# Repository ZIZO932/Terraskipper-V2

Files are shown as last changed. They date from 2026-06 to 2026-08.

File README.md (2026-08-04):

# Terraskipper V2 

> A mudskipper-inspired soft robot built to help farmers monitor and understand their soil

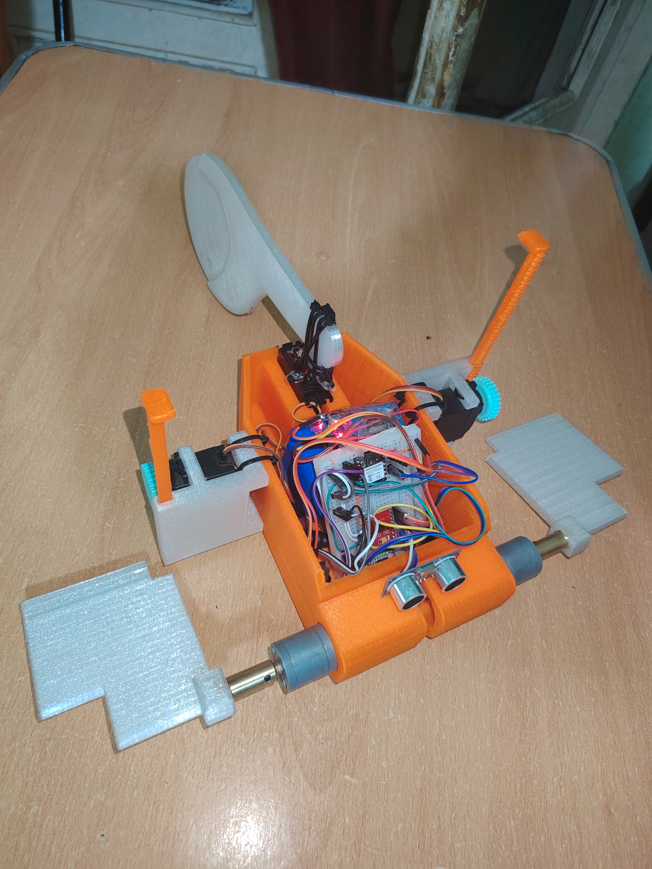
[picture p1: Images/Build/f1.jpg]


---

## What is this?

Terraskipper is a robot that moves like a mudskipper fish. It crawls on mud and uneven ground using fins powered by DC motors and servos. While it moves around it collects soil data like pH levels, moisture, salinity and other environmental readings.

The whole idea came from a real problem. The Nile Delta in Egypt is facing serious soil degradation. Salt levels are rising and pH is shifting in ways that hurt farming. Most monitoring tools cant really reach difficult terrain or muddy areas. Terraskipper can.

The robot is designed to go where normal sensors cant and give farmers useful data about their land without them having to do much.

---

## Why I made it

I wanted to build something that actually solves a problem in the real world not just a cool robot for the sake of it. Agriculture in Egypt especially near the Nile Delta depends on soil quality and right now that soil is changing in ways that are hard to track.

A mudskipper felt like the perfect inspiration because it literally evolved to handle the transition between water and land which is exactly the kind of terrain that is hard for robots to deal with.

---

## Build Process

After the design was done I moved on to actually building it. A lot of stuff that worked on screen didnt work the same in real life.

- Rebuilt the circuit from the schematic one component at a time, testing power, then the Pico, then each sensor one by one (moisture, TDS, temperature, the 3 ultrasonics) so debugging was easier.
- Got PCB review feedback: add screw mounting, clean up and round the layout, include Gerber files, add the missing sensors to the CAD. Fixed all of it and gave the PCB its own mounting spot in the 3D model.
- Assembled the robot: joined the two printed body halves, built the sensor placement mechanism, mounted the motors and fins, then fit the PCB and wired everything inside the body.
- Tested the full system and tested power, sensors, and movement again after assembly to catch anything that shifted.
- Uploaded and ran the code function by function. Found the right DC motor wasnt moving, swapped both motors to confirm it wasnt the motor itself, traced it to the motor driver's motor B output, and fixed it.
- Did a final pass before filming: checked all connections, cleaned up the wiring, and ran through the movements a few times to make sure they'd look good on camera.

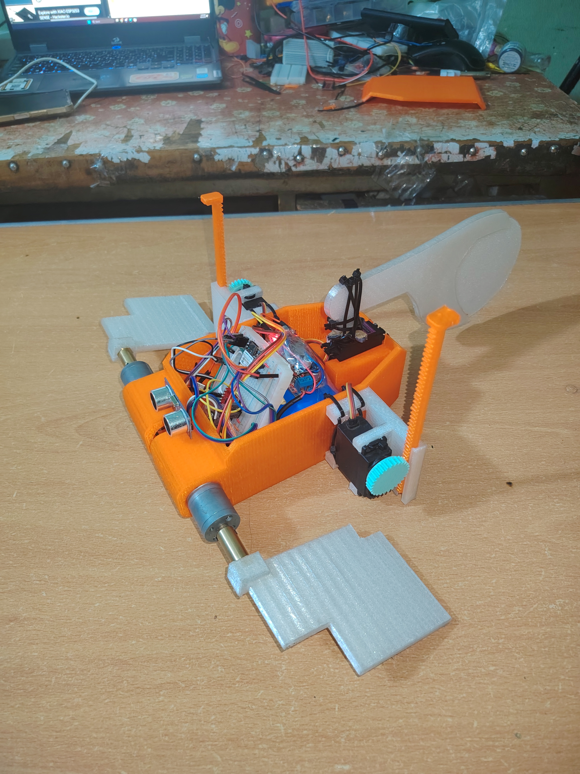
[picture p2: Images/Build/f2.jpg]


---

## The Final Build

after the first prototype i went back and reprinted the whole body smaller than before. still fits everything inside the same as before, just uses less filament and ends up alot lighter overall. checked all the parts lined up right after printing and made a couple small tweaks where they didnt.

that was really the only change from the first prototype to the final one, just the size.

---

## How it works

The robot has two main systems working together

**Movement system**
- Two JGB37-520 DC Geared Motors (12V 37RPM with encoders) power the pectoral fins for forward movement
- One servo controls the caudal fin for steering
- Two more servos handle the sensor placement mechanism so the sensors can move up and down to properly contact the soil

**Sensor system**
- 3x HC-SR04 ultrasonic sensors for obstacle detection and movement awareness (removed two in the final because one of them wasnt working for no reason)
- MPU-6050 IMU for tilt and orientation tracking using gyroscope and accelerometer
- Ublox NEO-7M GPS module for location tracking
- Capacitive soil moisture sensor V2.0 for soil water content readings
- DS18B20 waterproof temperature sensor for soil temperature

**Brain**
- Raspberry Pi Pico 2 W handles everything

---

## The 3D Model

For the body i made sure that all edges have fillets and chamfers so the robot doesnt damage the soil while crawling.

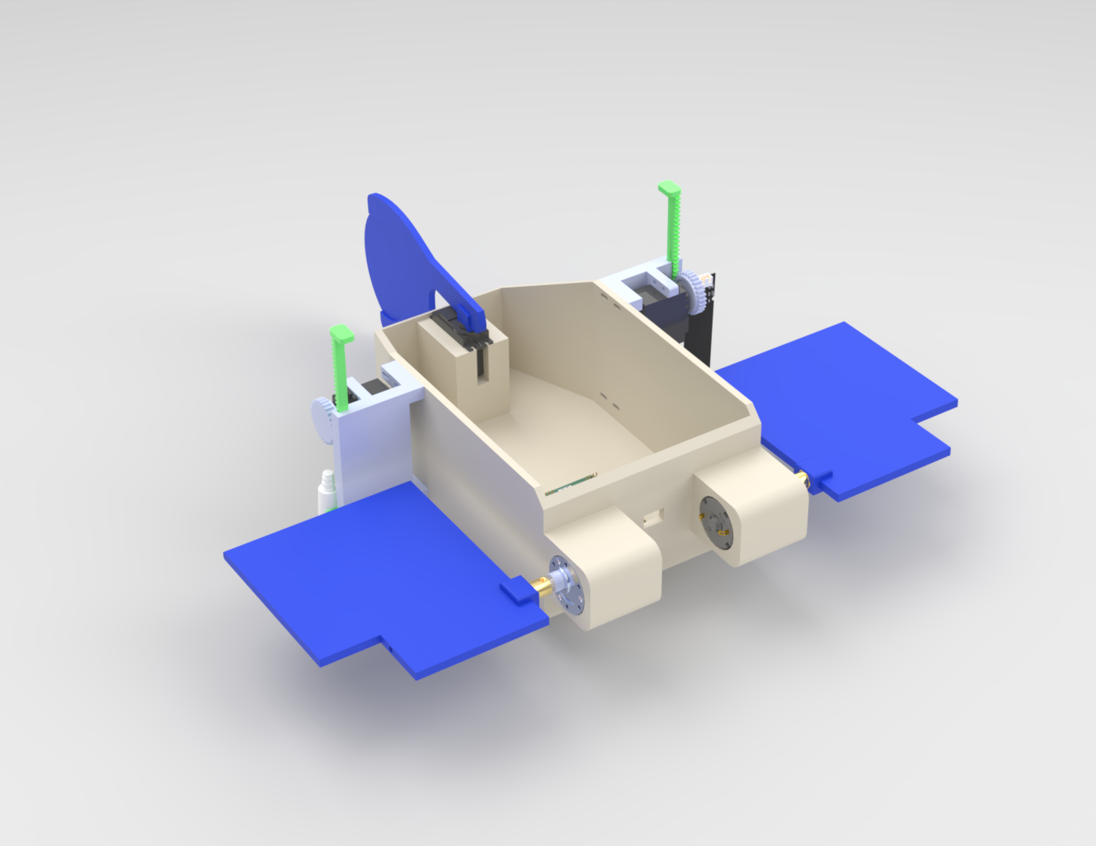
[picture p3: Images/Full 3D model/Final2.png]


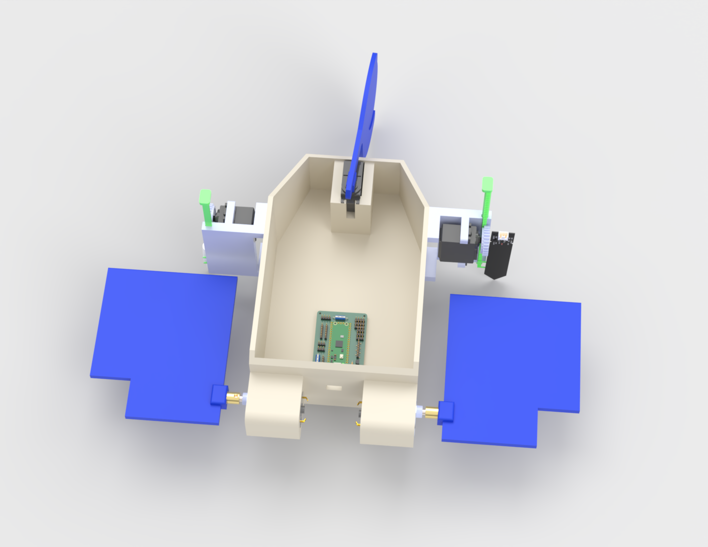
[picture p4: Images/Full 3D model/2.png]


The sensor placement mechanism uses a mini linear slider with a servo motor so the sensors can move vertically and make proper contact with different soil surfaces. The mechanism is also detachable so it can be removed for repairs without taking apart the whole robot.

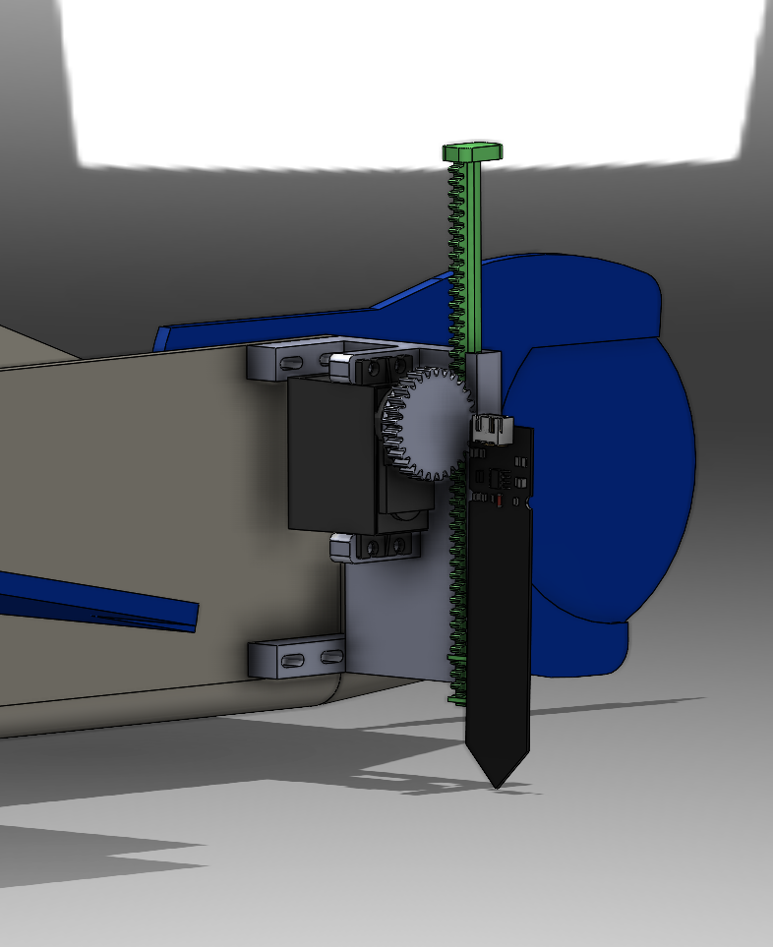
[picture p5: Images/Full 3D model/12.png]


---

## PCB & Electronics

The PCB is a 2-layer board. Top layer carries signal lines and positive voltage. Bottom layer is a full GND plane to keep things clean and reduce noise.

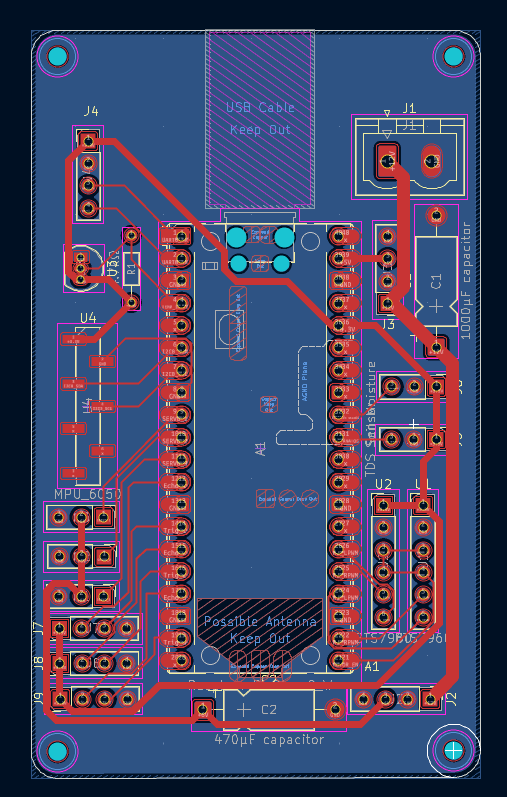
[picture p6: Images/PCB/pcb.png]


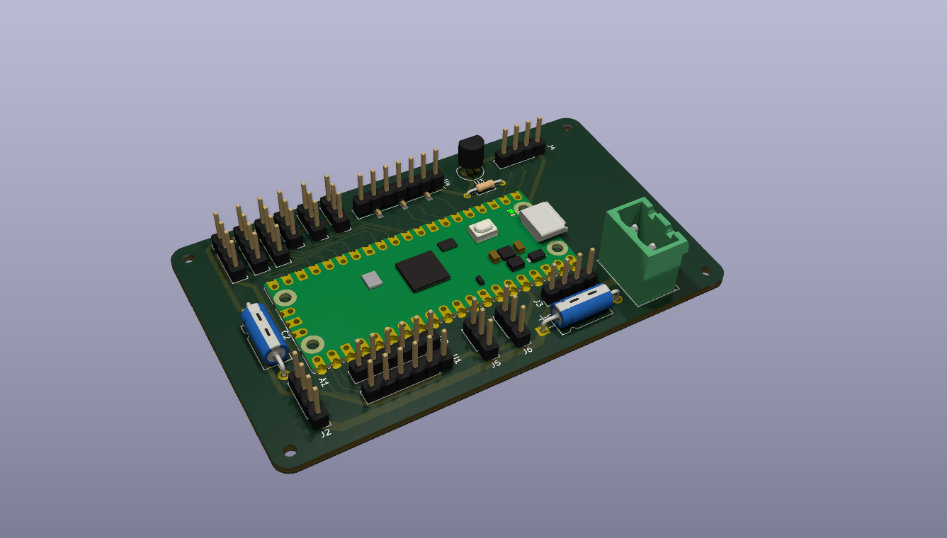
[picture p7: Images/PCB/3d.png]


Main components on the board:

- Xiao esp S3
- 2x BTS7960 43A motor drivers (one per DC motor)
- XL4016 8A and LM2596 3A buck converters for power regulation
- MPU-6050 IMU gyro and accelerometer
- Ublox NEO-7M GPS module
- Capacitive soil moisture sensor V2.0
- DS18B20 waterproof temperature sensor
- 3x HC-SR04 ultrasonic sensors

All sensors run on 3.3V logic to match the Pico 2 W. Power comes from the buck converters and sensors pull directly from the Pico 3.3V output.

---

## Wiring

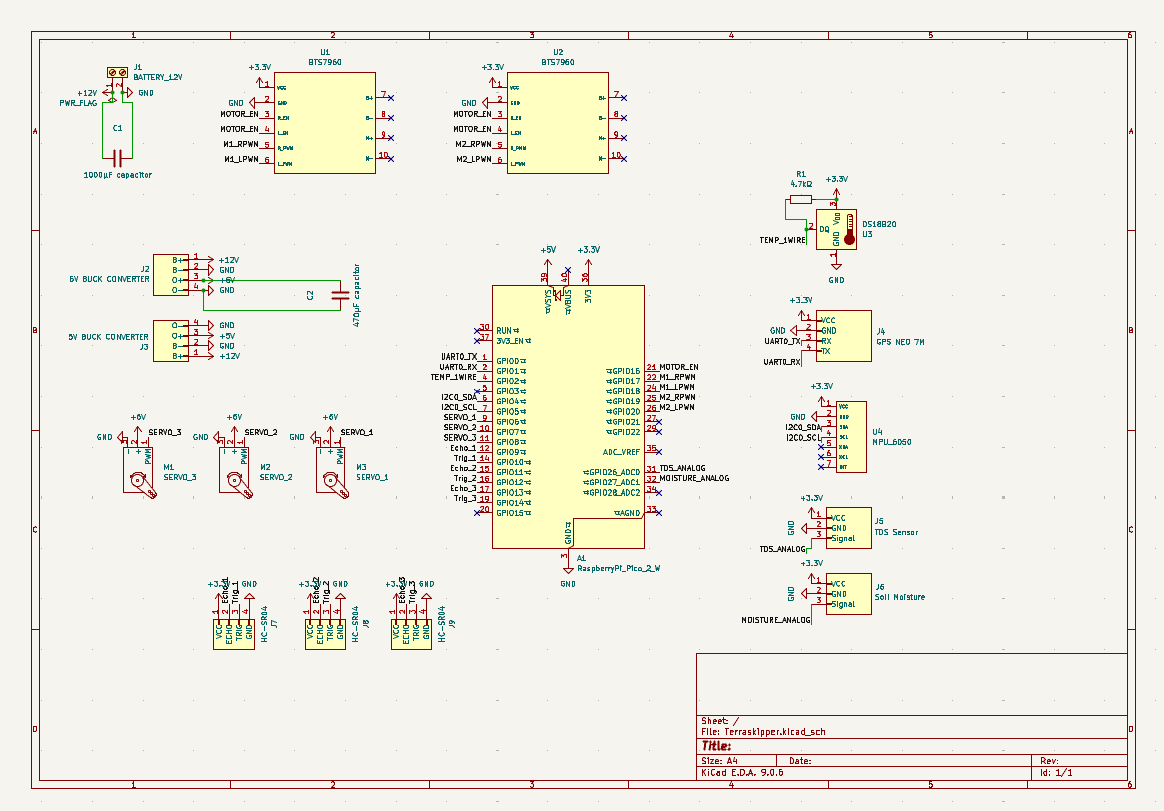
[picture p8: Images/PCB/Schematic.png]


All connections go through the custom PCB. Motor drivers connect directly to the DC motors and are controlled via PWM from the Pico.

---

## Bill of Materials

18 components total. Estimated cost around **$102.50 USD / 5,315 EGP**

| Component | Category | Qty | Unit Price (EGP) | Total (EGP) |
|---|---|---|---|---|
| Raspberry pi Pico 2w | Microcontroller | 1 | 900 | 900 |
| BTS7960 43A DC Motor Driver | Motor Driver | 2 | 450 | 900 |
| MG996R 360° Servo Motor | Motors | 3 | 210 | 630 |
| DC Motor With Gear Box JGA25-370 12V 33RPM 30Kg.cm | Motors | 2 | 300 | 600 |
| Ublox NEO-7M GPS Module | Sensors | 1 | 540 | 540 |
| MPU-6050 IMU Gyro/Accel Module | Sensors | 1 | 175 | 175 |
| Capacitive Soil Moisture Sensor V2.0 | Sensors | 1 | 100 | 100 |
| DS18B20 Waterproof Temp Sensor | Sensors | 1 | 85 | 85 |
| HC-SR04 Ultrasonic Sensor | Sensors | 3 | 40 | 120 |
| Rechargeable Li-ion Battery Pack 18650 12V 6000mAh | Power | 1 | 900 | 900 |
| XL4016 8A Step-Down Buck Converter | Power | 1 | 243 | 243 |
| LM2596 3A Step-Down Buck Converter | Power | 1 | 122 | 122 |
| **Total** | | **18** | | **5,315 EGP** |

---

## Magazine / Zine
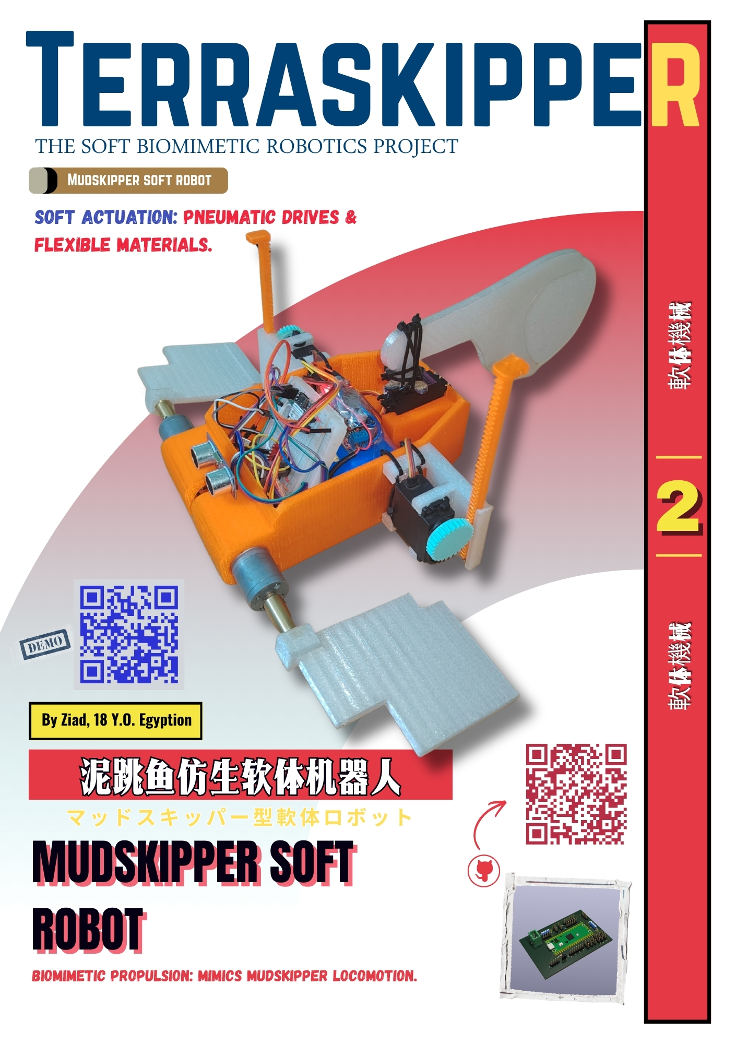
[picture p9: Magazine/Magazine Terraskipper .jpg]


## Demo video

https://youtube.com/shorts/rW8oGuy9Nso

---

## Build Progress

The robot went through a lot of iterations. Some highlights:

- Switched from ESP32 to Raspberry Pi Pico 2 W midway through because it uses Python which is way better for me and had easier integration
- Replaced front servo motors with DC geared motors for more torque
- Rebuilt the schematic from scratch after finding SMD components weren't practical
- Redesigned the body twice to reduce filament usage and fit standard printer sizes
- Learned PID control to improve movement stability
- Took the PCB through a full review round, fixing mounting, layout, and Gerber file gaps
- Got the full system running together for the first time and debugged a motor driver fault on the way
- Reprinted the body smaller for the final version to cut weight and material

---

## Made by

Ziad — as part of a project exploring how robotics and soft robot design can support smart farming and environmental monitoring in Egypt

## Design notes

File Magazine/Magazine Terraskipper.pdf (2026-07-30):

T

e

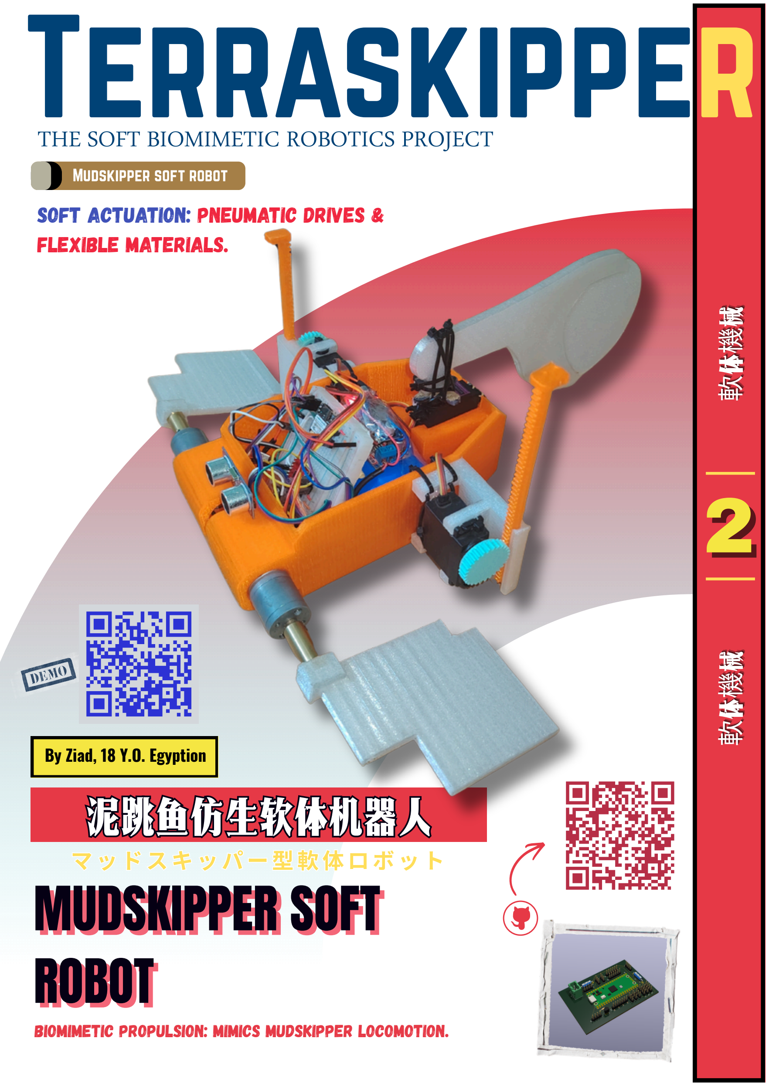
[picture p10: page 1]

泥跳鱼仿生软体机器人 マッドスキッパー型軟体ロボット MUDSKIPPER SOFT

ROBOT

MUDSKIPPER SOFT
ROBOT

Biomimetic Propulsion: Mimics mudskipper locomotion.

THE

SOFT

r

BIOMI

r

METIC

a

ROBO

s

TICS P

k

ROJEC

i

T

# pper

Mudskipper soft robot

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
By Ziad, 18 Y.O. Egyption

Soft Actuation: Pneumatic drives & flexible materials.

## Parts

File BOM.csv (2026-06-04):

Component Name | Category | Unit Price (EGP) | Quantity | Total Price (EGP) | Unit Price (USD) | Total Price (USD) | Store Name | Sourcing Link
Raspberry Pi Pico 2 W | Microcontroller | 900.00 EGP | 1 | 900.00 EGP | $17.36 | $17.36 | Dev Boards | https://devboardsmarket.com/products/raspberry-pi-pico-2-w
BTS7960 43A DC Motor Driver | Motor Drivers | 450.00 EGP | 2 | 900.00 EGP | $8.68 | $17.36 | Most electronics | https://mostelectronic.com/shop/motors-drives-2/dc-motor-driver-bts7960-single-channel-43a/
MG996R 360° Servo Motor | Motors & Actuators | 210.00 EGP | 3 | 630.00 EGP | $4.05 | $12.15 | Ram electronics | https://www.ram-e-shop.com/ar/shop/servo-mg996-360-mg996r-servo-motor-360deg-11-kg-cm-metal-gears-9061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
HC-SR04 Ultrasonic Sensor | Sensors | 40.00 EGP | 3 | 120.00 EGP | $0.77 | $2.31 | Ram electronics | https://www.ram-e-shop.com/ar/shop/kit-ultrasonic-hcsr04-ultrasonic-sensor-hc-sr04-5949
Ublox NEO-7M GPS Module | Sensors | 540.00 EGP | 1 | 540.00 EGP | $10.41 | $10.41 | Micro ohm | https://microohm-eg.com/ublox-neo-7m-gps-module-hw-623-with-micro-usb/
MPU-6050 IMU Gyro/Accel Module | Sensors | 175.00 EGP | 1 | 175.00 EGP | $3.38 | $3.38 | Ram electronics | https://www.ram-e-shop.com/ar/shop/kit-imu-mpu6050-gy521-imu-6-dof-mpu-6050-gyroscope-accelerometer-sensor-module-7076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
DS18B20 Waterproof Temp Sensor | Sensors | 85.00 EGP | 1 | 85.00 EGP | $1.64 | $1.64 | Ram electronics | https://www.ram-e-shop.com/ar/shop/wire-ds18b20-ds18b20-waterproof-temperature-sensor-original-chip-7175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
Capacitive Soil Moisture Sensor V2.0 | Sensors | 100.00 EGP | 1 | 100.00 EGP | $1.93 | $1.93 | Ram electronics | https://www.ram-e-shop.com/ar/shop/sen-soil-c-capacitive-analog-soil-moisture-sensor-v2-0-sku-soil-c-8116
XL4016 8A Step-Down Buck Converter | Power Management | 242.99 EGP | 1 | 242.99 EGP | $4.69 | $4.69 | Most electronics | https://mostelectronic.com/shop/dc-ac-converters/xl4016-dc-dc-buck-converter-8a-step-down-4-36v-to-1-25-36v-with-display/
LM2596 3A Step-Down Buck Converter | Power Management | 121.99 EGP | 1 | 121.99 EGP | $2.35 | $2.35 | Most electronics | https://mostelectronic.com/shop/dc-ac-converters/dc-dc-step-down-adjustable-voltage-converter-module-with-display-3a-lm2596/
DC Motor With Gear Box JGA25-370-12V-33RPM 30Kg.cm | Motors & Actuators | 300.00 EGP | 2 | 600.00 EGP | $5.79 | $11.57 | Makers electronics | https://makerselectronics.com/product/dc-motor-with-gear-box-jga25-370-12v-33rpm-30kg-cm/
Rechargeable Original New Li-ion Battery Pack -18650 12V 3S-2P+BMS 6000mAh | Power Management | 900.00 EGP | 1 | 900.00 EGP | $17.36 | $17.36 | Makers electronics | https://makerselectronics.com/product/rechargeable-original-new-li-ion-battery-pack-18650-12v-3s-2pbms-6000mah/
Total Summary |  |  | 18 | 5,314.98 EGP |  | $102.51

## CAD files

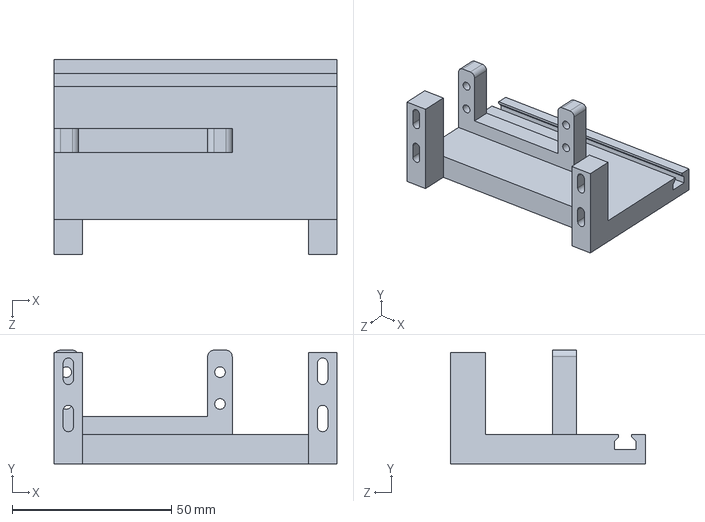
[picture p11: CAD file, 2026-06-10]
3D Model Parts/Sensor placement Body.SLDPRT
88.9 x 35.7 x 61.2 mm

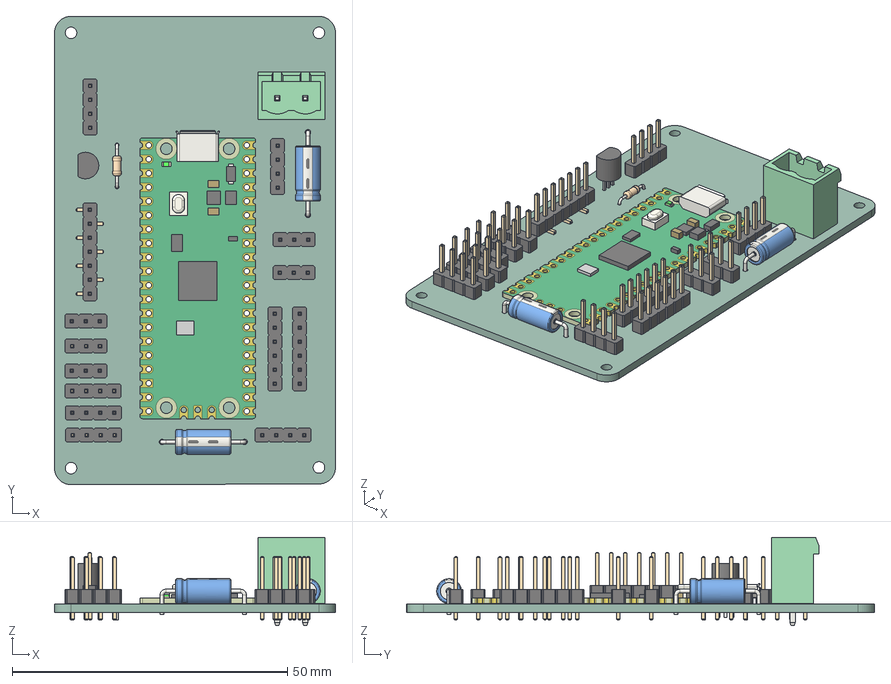
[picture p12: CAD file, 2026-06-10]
Schematic & PCB/Terraskipper.step
51.0 x 85.0 x 16.0 mm
R_Axial_DIN0204_L3.6mm_D1.6mm_P7.62mm_Horizontal
PinHeader_1x04_P2.54mm_Vertical x 6
CP_Axial_L10.0mm_D4.5mm_P15.00mm_Horizontal x 2
PinHeader_1x06_P2.54mm_Vertical x 2
RaspberryPi_Pico_Module_KiCad
PinHeader_1x03_P2.54mm_Vertical x 5
PhoenixContact_MSTBVA_2,5_2-G-5,08_1x02_P5.08mm_Vertical
PinHeader_1x07_P2.54mm_Vertical_SMD_Pin1Left
TO-92_Inline
Terraskipper_PCB

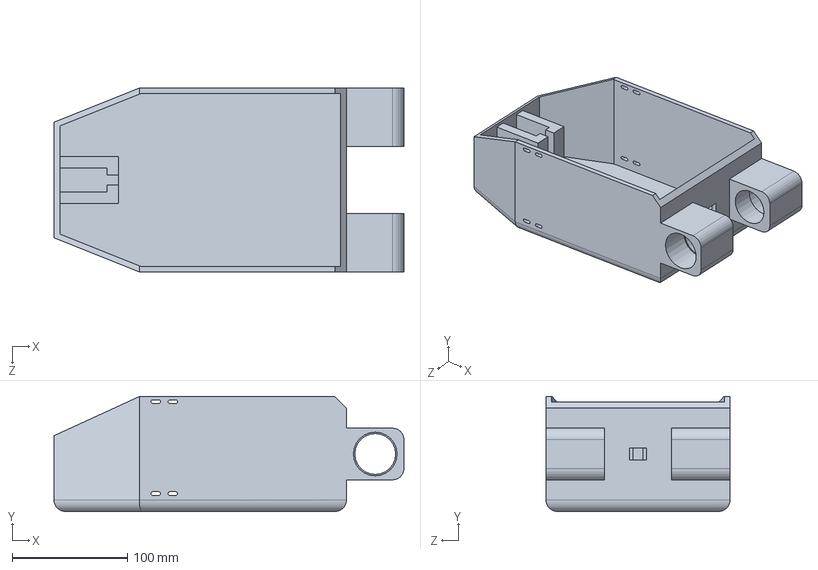
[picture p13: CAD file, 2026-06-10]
3D Model Parts/Body with dc holders.SLDPRT
304.3 x 100.0 x 160.0 mm

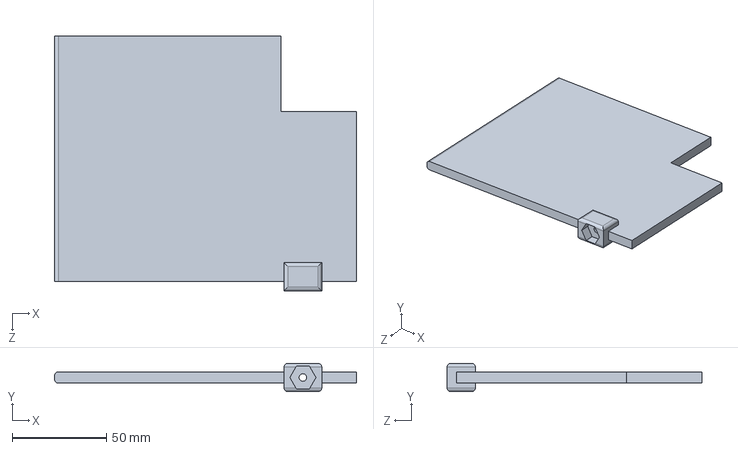
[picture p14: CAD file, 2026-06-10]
3D Model Parts/Pectrol fin.SLDPRT
160.0 x 15.0 x 135.0 mm

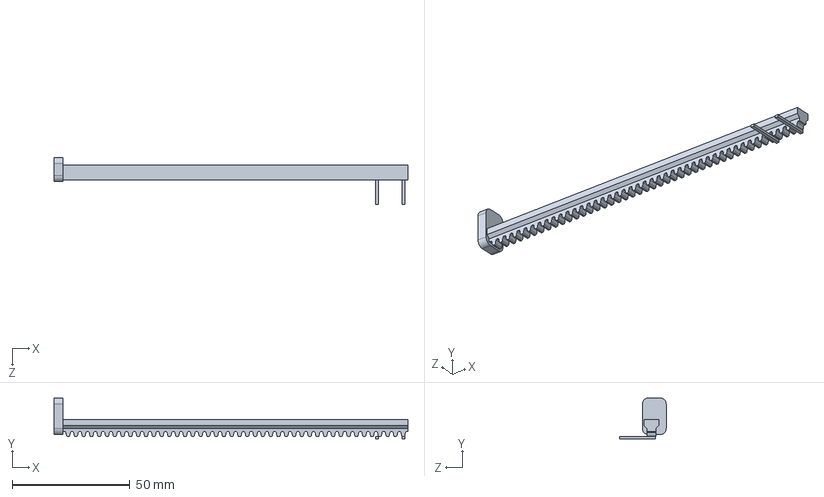
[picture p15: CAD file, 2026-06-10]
3D Model Parts/Pusher, 150mm Long.SLDPRT
150.0 x 17.4 x 19.7 mm

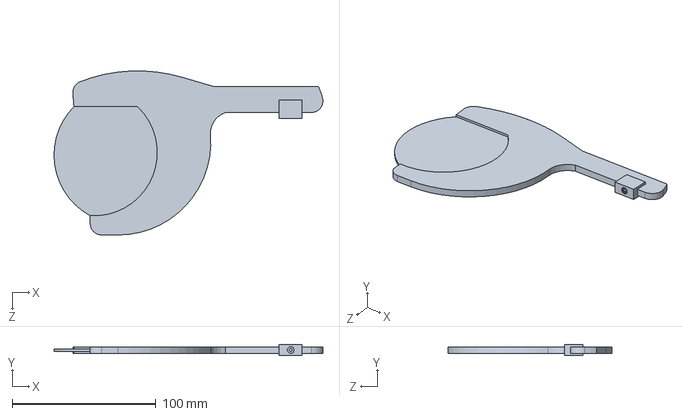
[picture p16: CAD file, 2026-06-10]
3D Model Parts/Claudel fin.SLDPRT
187.3 x 8.00 x 114.2 mm

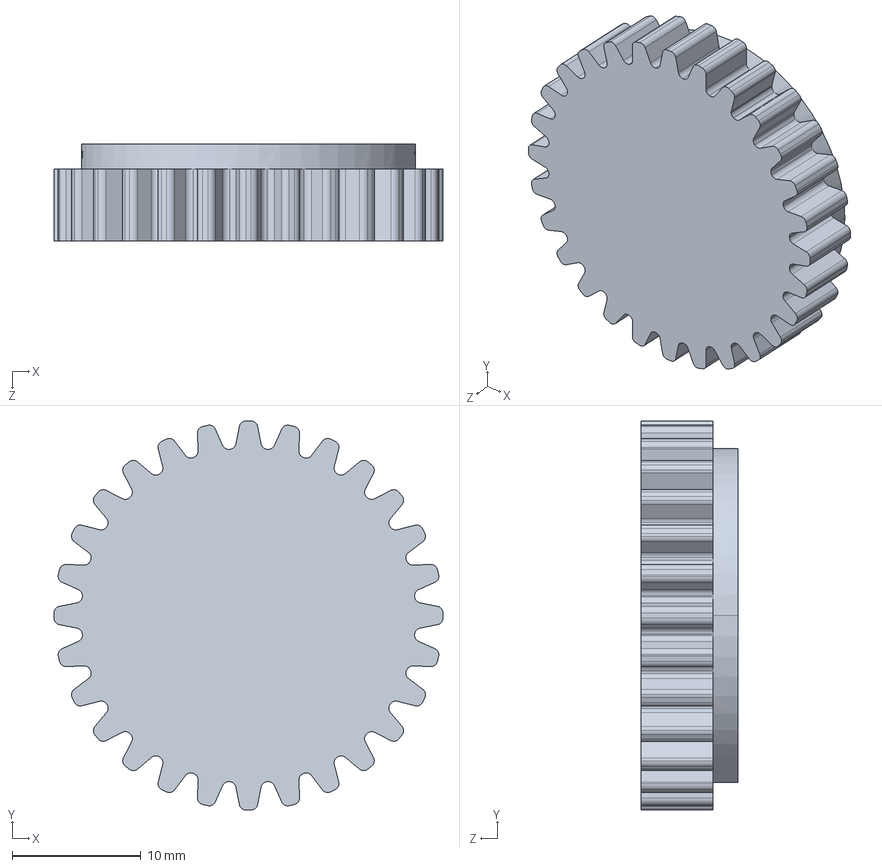
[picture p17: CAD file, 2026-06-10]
3D Model Parts/gear.SLDPRT
30.2 x 30.2 x 7.51 mm

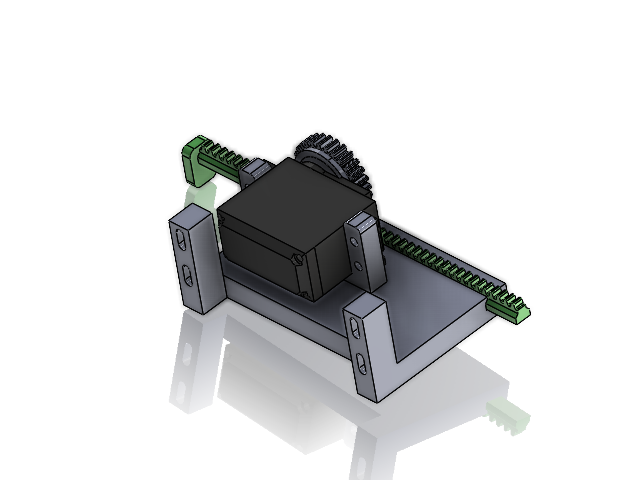
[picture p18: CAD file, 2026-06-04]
CAD/Sensor placement by itself.SLDASM
MG996R_servo
Sensor placement Body
Pusher, 150mm Long.step
gear

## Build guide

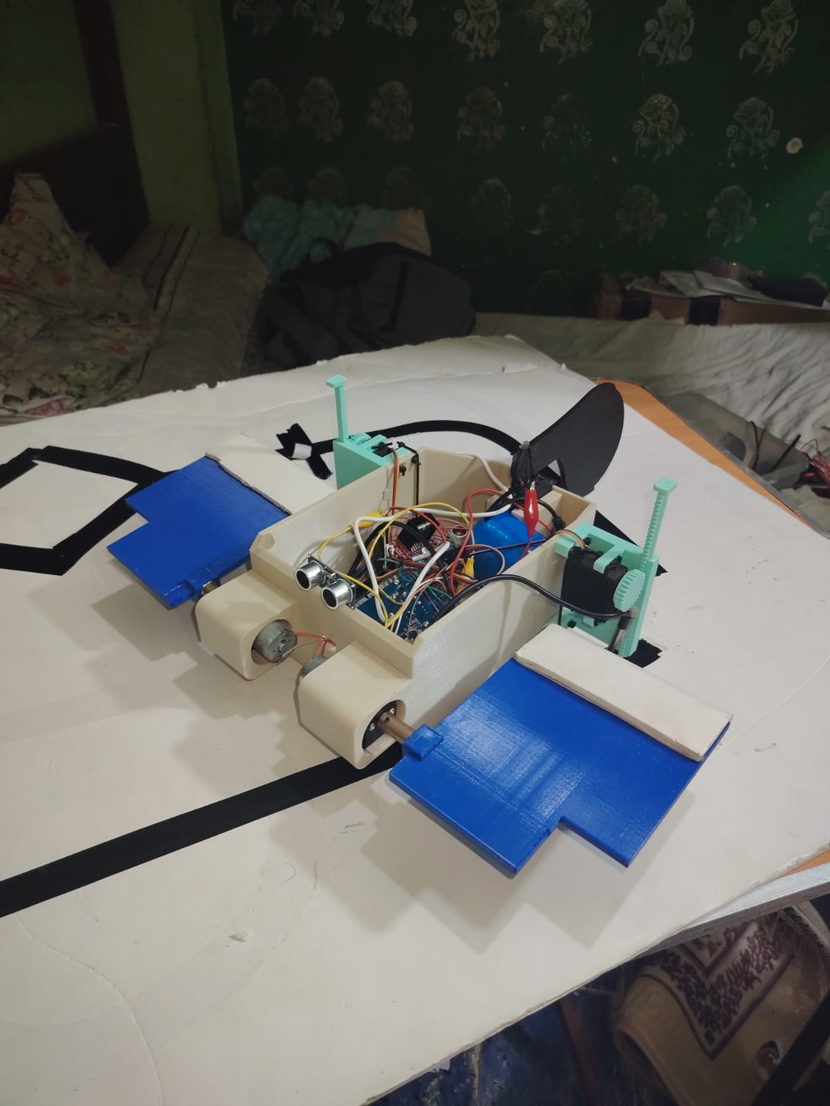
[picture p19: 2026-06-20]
Images/Build/m8.jpeg

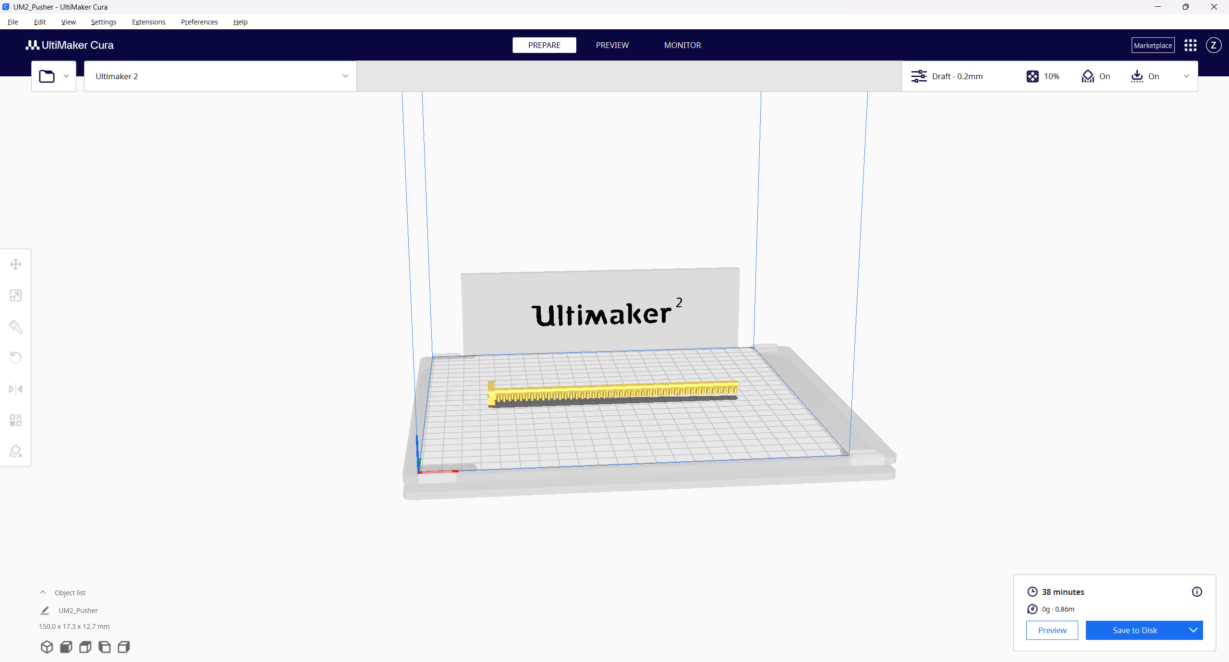
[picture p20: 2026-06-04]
Images/UltiMaker/Pusher.png

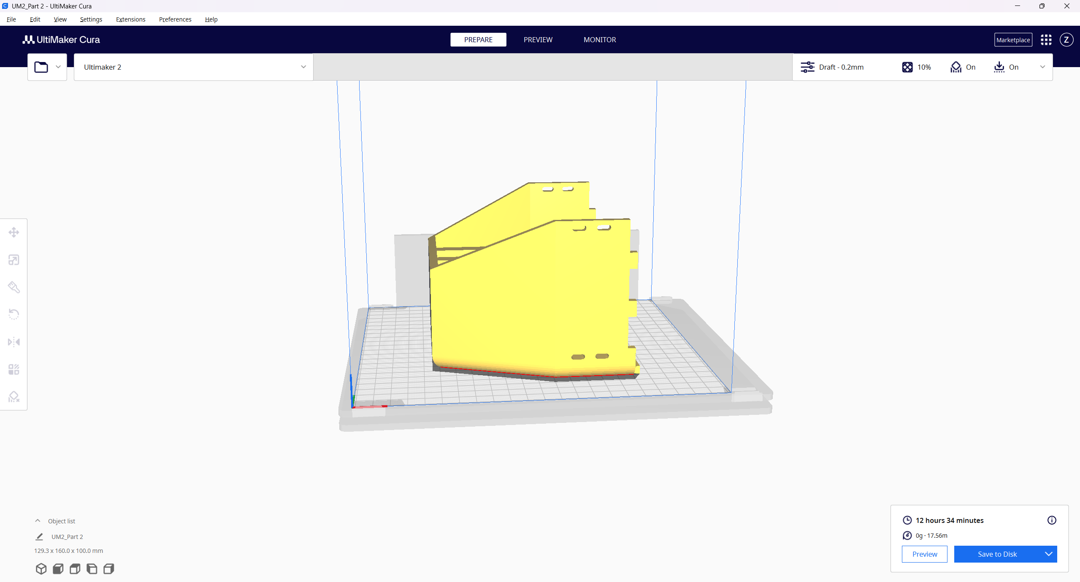
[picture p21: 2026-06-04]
Images/UltiMaker/Body part 2.png

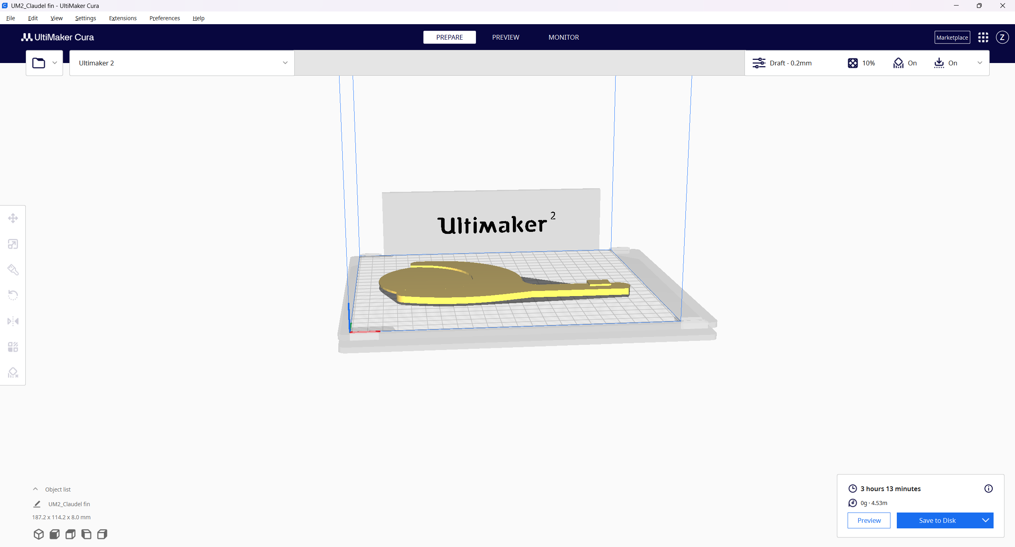
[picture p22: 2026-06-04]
Images/UltiMaker/Claudel fin.png

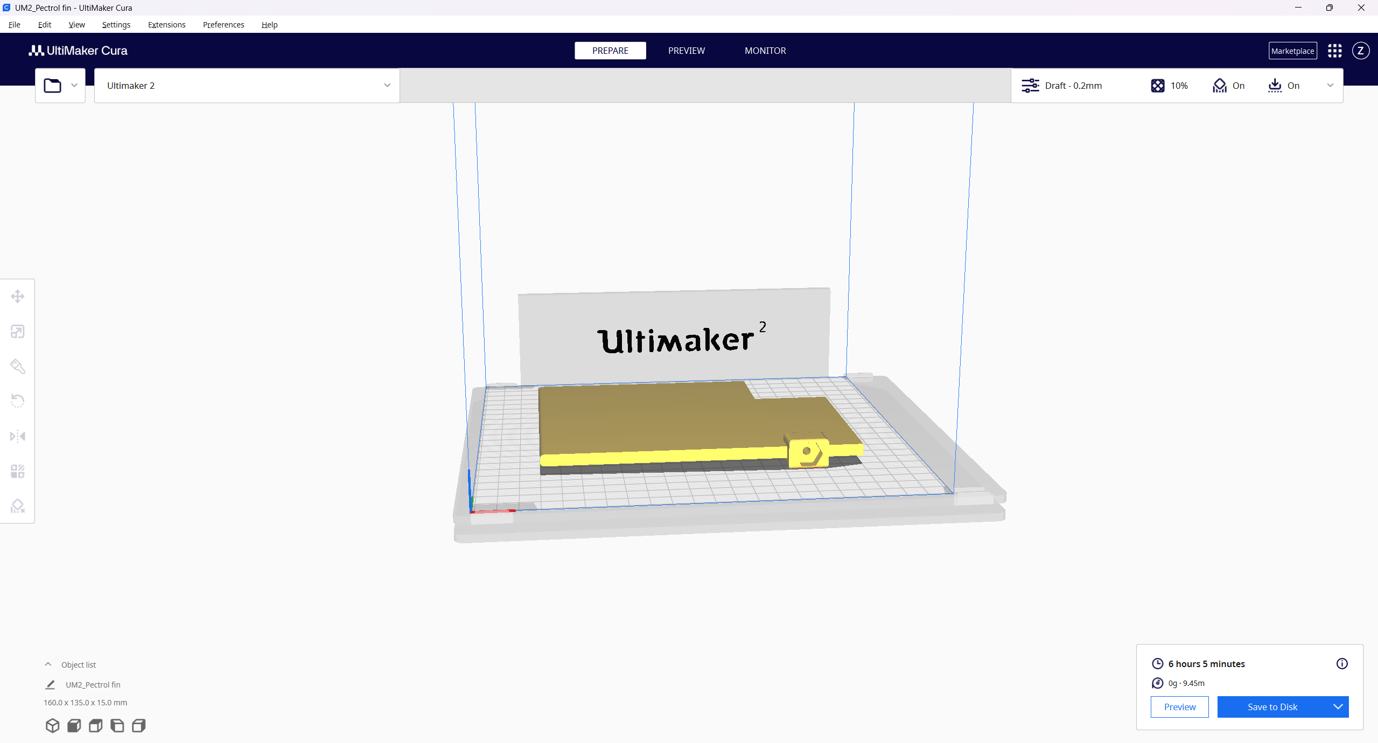
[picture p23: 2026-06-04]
Images/UltiMaker/Pectrol fin.png

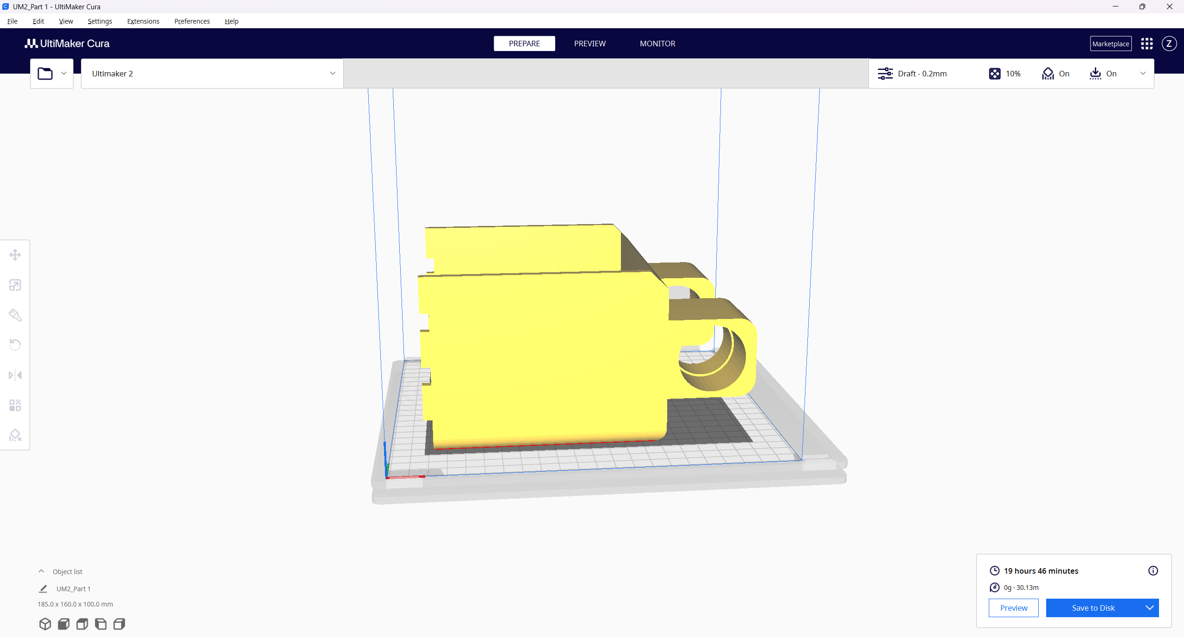
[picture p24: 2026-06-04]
Images/UltiMaker/Body part 1.png

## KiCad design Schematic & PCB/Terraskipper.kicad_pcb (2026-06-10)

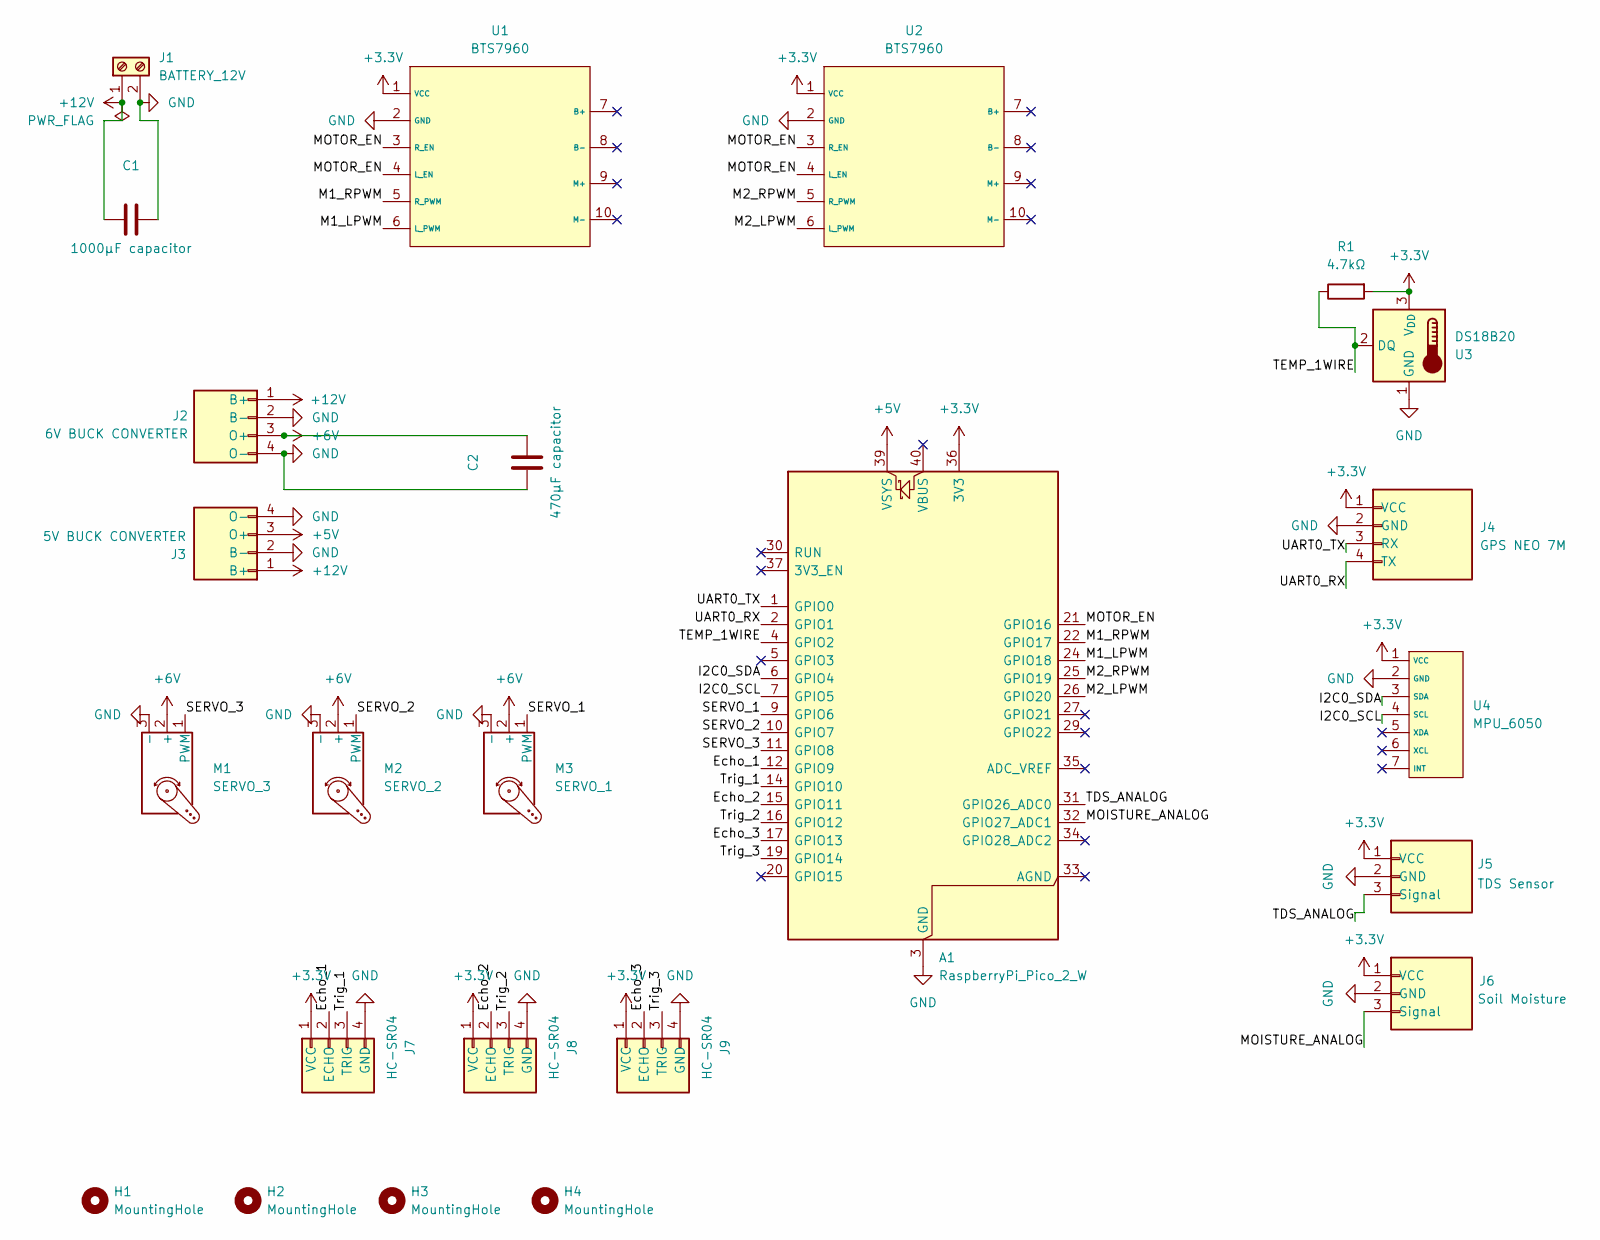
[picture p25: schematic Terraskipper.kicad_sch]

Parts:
A1: RaspberryPi_Pico_2_W; RaspberryPi_Pico_Common_Unspecified
C1: 1000µF capacitor; CP_Axial_L10.0mm_D4.5mm_P15.00mm_Horizontal
C2: 470µF capacitor; CP_Axial_L10.0mm_D4.5mm_P15.00mm_Horizontal
H1, H2, H3, H4: MountingHole; MountingHole_2.1mm
J1: BATTERY_12V; PhoenixContact_MSTBVA_2,5_2-G-5,08_1x02_P5.08mm_Vertical
J2: 6V BUCK CONVERTER; PinHeader_1x04_P2.54mm_Vertical
J3: 5V BUCK CONVERTER; PinHeader_1x04_P2.54mm_Vertical
J4: GPS NEO 7M; PinHeader_1x04_P2.54mm_Vertical
J5: TDS Sensor; PinHeader_1x03_P2.54mm_Vertical
J6: Soil Moisture; PinHeader_1x03_P2.54mm_Vertical
J7, J8, J9: HC-SR04; PinHeader_1x04_P2.54mm_Vertical
M1: SERVO_3; PinHeader_1x03_P2.54mm_Vertical
M2: SERVO_2; PinHeader_1x03_P2.54mm_Vertical
M3: SERVO_1; PinHeader_1x03_P2.54mm_Vertical
R1: 4.7kΩ; R_Axial_DIN0204_L3.6mm_D1.6mm_P7.62mm_Horizontal
U1, U2: BTS7960; PinHeader_1x06_P2.54mm_Vertical
U3: DS18B20; TO-92_Inline
U4: MPU_6050; PinHeader_1x07_P2.54mm_Vertical_SMD_Pin1Left

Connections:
+3.3V: A1.36 (3V3), J4.1 (VCC), J5.1 (VCC), J6.1 (VCC), J7.1 (VCC), J8.1 (VCC), J9.1 (VCC), R1.2, U1.1 (VCC), U2.1 (VCC), U3.3 (V_{DD}), U4.1 (VCC)
+5V: A1.39 (VSYS), J3.3 (O+)
+6V: C2.1, J2.3 (O+), M1.2 (+), M2.2 (+), M3.2 (+)
+12V: C1.1, J1.1, J2.1 (B+), J3.1 (B+)
/Echo_1: A1.12 (GPIO9), J7.2 (ECHO)
/Echo_2: A1.15 (GPIO11), J8.2 (ECHO)
/Echo_3: A1.17 (GPIO13), J9.2 (ECHO)
/I2C0_SCL: A1.7 (GPIO5), U4.4 (SCL)
/I2C0_SDA: A1.6 (GPIO4), U4.3 (SDA)
/M1_LPWM: A1.24 (GPIO18), U1.6 (L_PWM)
/M1_RPWM: A1.22 (GPIO17), U1.5 (R_PWM)
/M2_LPWM: A1.26 (GPIO20), U2.6 (L_PWM)
/M2_RPWM: A1.25 (GPIO19), U2.5 (R_PWM)
/MOISTURE_ANALOG: A1.32 (GPIO27_ADC1), J6.3 (Signal)
/MOTOR_EN: A1.21 (GPIO16), U1.3 (R_EN), U1.4 (L_EN), U2.3 (R_EN), U2.4 (L_EN)
/SERVO_1: A1.9 (GPIO6), M3.1 (PWM)
/SERVO_2: A1.10 (GPIO7), M2.1 (PWM)
/SERVO_3: A1.11 (GPIO8), M1.1 (PWM)
/TDS_ANALOG: A1.31 (GPIO26_ADC0), J5.3 (Signal)
/TEMP_1WIRE: A1.4 (GPIO2), R1.1, U3.2 (DQ)
/Trig_1: A1.14 (GPIO10), J7.3 (TRIG)
/Trig_2: A1.16 (GPIO12), J8.3 (TRIG)
/Trig_3: A1.19 (GPIO14), J9.3 (TRIG)
/UART0_RX: A1.2 (GPIO1), J4.4 (TX)
/UART0_TX: A1.1 (GPIO0), J4.3 (RX)
GND: A1.3 (GND), A1.8 (GND), A1.13 (GND), A1.18 (GND), A1.23 (GND), A1.28 (GND), A1.38 (GND), C1.2, C2.2, J1.2, J2.2 (B-), J2.4 (O-), J3.2 (B-), J3.4 (O-), J4.2 (GND), J5.2 (GND), J6.2 (GND), J7.4 (GND), J8.4 (GND), J9.4 (GND), M1.3 (-), M2.3 (-), M3.3 (-), U1.2 (GND), U2.2 (GND), U3.1 (GND), U4.2 (GND)

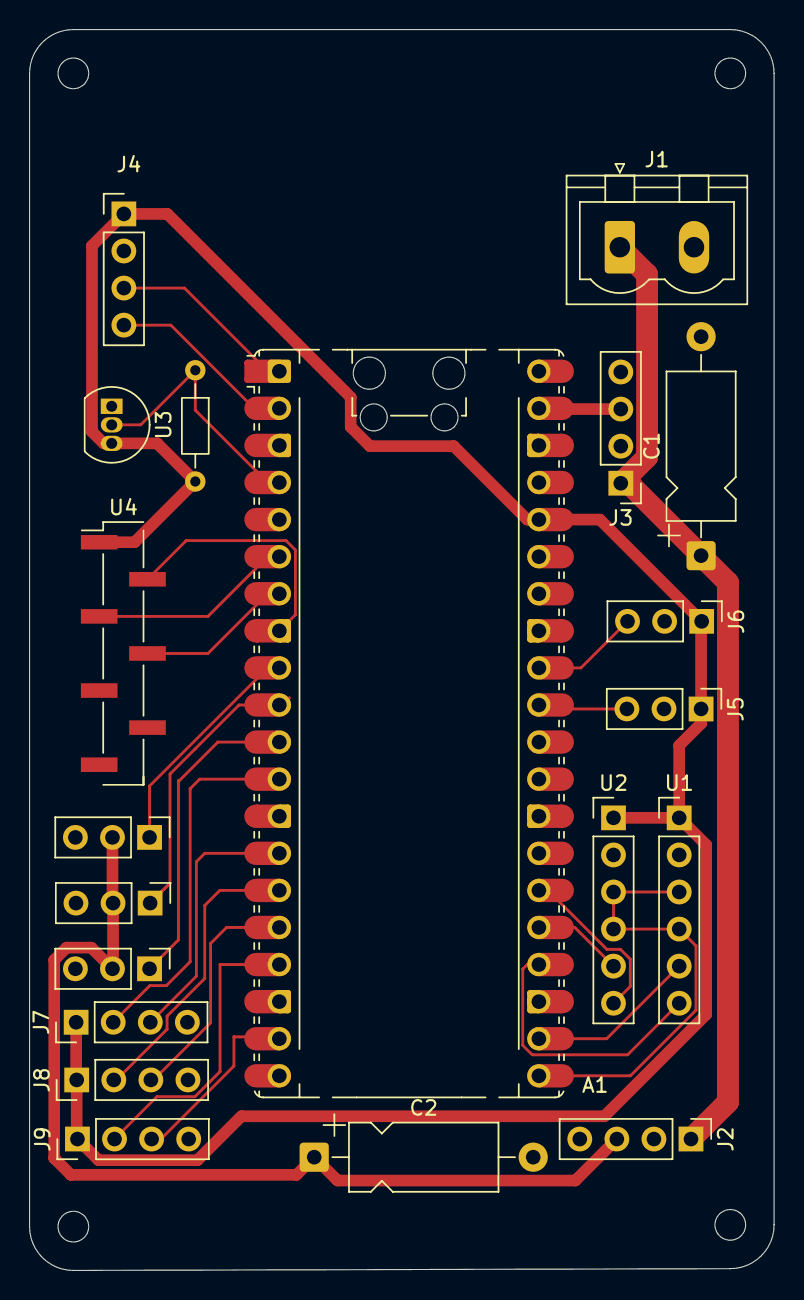
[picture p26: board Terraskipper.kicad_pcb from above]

Board: 2 copper layers, 51.0 x 85.0 mm, 24 parts (0 on the bottom side), 26 nets.

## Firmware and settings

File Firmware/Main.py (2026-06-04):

import time
import struct
import math
from machine import Pin, PWM, ADC, I2C

LOOP_HZ          = 10
LOOP_PERIOD_MS   = 1000 // LOOP_HZ
SOUND_CM_PER_US  = 0.01716
HCSR04_TIMEOUT   = 30_000
MOTOR_PWM_FREQ   = 20_000
MOTOR_DUTY_FULL  = 65535
SERVO_FREQ       = 50
SERVO_PERIOD_US  = 20_000
MPU_ADDR         = 0x68
MPU_PWR_MGMT_1   = 0x6B
MPU_SMPLRT_DIV   = 0x19
MPU_CONFIG_REG   = 0x1A
MPU_GYRO_CONFIG  = 0x1B
MPU_ACCEL_CONFIG = 0x1C
MPU_ACCEL_XOUT_H = 0x3B
MPU_WHO_AM_I     = 0x75
ACCEL_SCALE      = 16384.0
GYRO_SCALE       = 131.0
OW_SKIP_ROM      = 0xCC
OW_CONVERT_T     = 0x44
OW_READ_SCRATCH  = 0xBE
VREF             = 3.3
ADC_MAX          = 65535
TEMP_COMP_COEFF  = 0.02
MOISTURE_DRY_RAW = 52000
MOISTURE_WET_RAW = 18000

ena = PWM(Pin(16)); ena.freq(MOTOR_PWM_FREQ); ena.duty_u16(0)
in1 = Pin(17, Pin.OUT, value=0)
in2 = Pin(18, Pin.OUT, value=0)
in3 = Pin(19, Pin.OUT, value=0)
in4 = Pin(20, Pin.OUT, value=0)
enb = PWM(Pin(21)); enb.freq(MOTOR_PWM_FREQ); enb.duty_u16(0)

sv1 = PWM(Pin(6));  sv1.freq(SERVO_FREQ)
sv2 = PWM(Pin(7));  sv2.freq(SERVO_FREQ)
sv3 = PWM(Pin(8));  sv3.freq(SERVO_FREQ)

echo1 = Pin(9,  Pin.IN);  trig1 = Pin(10, Pin.OUT, value=0)
echo2 = Pin(11, Pin.IN);  trig2 = Pin(12, Pin.OUT, value=0)
echo3 = Pin(13, Pin.IN);  trig3 = Pin(14, Pin.OUT, value=0)

adc_moisture = ADC(Pin(26))
adc_tds      = ADC(Pin(27))

i2c    = I2C(0, sda=Pin(4), scl=Pin(5), freq=400_000)
ow_pin = Pin(2)


def _us_duty(us):
    return int(us * 65535 // SERVO_PERIOD_US)

def servo_set_us(pwm, us):
    pwm.duty_u16(_us_duty(max(500, min(2500, us))))

def servo_angle(pwm, deg):
    servo_set_us(pwm, int(1000 + (deg / 180.0) * 1000))

def servo_cw(pwm, speed=1.0):
    servo_set_us(pwm, int(1500 - speed * 500))

def servo_stop(pwm):
    servo_set_us(pwm, 1500)


def motors_forward_full():
    in1.value(1); in2.value(0)
    in3.value(1); in4.value(0)
    ena.duty_u16(MOTOR_DUTY_FULL)
    enb.duty_u16(MOTOR_DUTY_FULL)

def motors_stop():
    ena.duty_u16(0); enb.duty_u16(0)
    in1.value(0); in2.value(0)
    in3.value(0); in4.value(0)


def hcsr04_measure(trig, echo):
    trig.value(0); time.sleep_us(2)
    trig.value(1); time.sleep_us(10)
    trig.value(0)
    t0 = time.ticks_us()
    while echo.value() == 0:
        if time.ticks_diff(time.ticks_us(), t0) > HCSR04_TIMEOUT:
            return -1.0
    t1 = time.ticks_us()
    while echo.value() == 1:
        if time.ticks_diff(time.ticks_us(), t1) > HCSR04_TIMEOUT:
            return -1.0
    t2 = time.ticks_us()
    return round(time.ticks_diff(t2, t1) * SOUND_CM_PER_US, 1)

def read_all_ultrasonic():
    d1 = hcsr04_measure(trig1, echo1)
    d2 = hcsr04_measure(trig2, echo2)
    d3 = hcsr04_measure(trig3, echo3)
    valid = [(n, d) for n, d in [("Sensor-1", d1), ("Sensor-2", d2), ("Sensor-3", d3)] if d >= 0]
    if valid:
        near_name, near_dist = min(valid, key=lambda x: x[1])
    else:
        near_name, near_dist = ("None", -1.0)
    return d1, d2, d3, near_name, near_dist


def _mpu_w(reg, val):
    i2c.writeto_mem(MPU_ADDR, reg, bytes([val]))

def _mpu_r(reg, n):
    return i2c.readfrom_mem(MPU_ADDR, reg, n)

def mpu_init_and_calibrate():
    print("[MPU] Resetting ...")
    _mpu_w(MPU_PWR_MGMT_1, 0x80)
    time.sleep_ms(150)
    _mpu_w(MPU_PWR_MGMT_1, 0x00)
    time.sleep_ms(50)
    _mpu_w(MPU_SMPLRT_DIV,   0x07)
    _mpu_w(MPU_CONFIG_REG,   0x03)
    _mpu_w(MPU_GYRO_CONFIG,  0x00)
    _mpu_w(MPU_ACCEL_CONFIG, 0x00)
    who = _mpu_r(MPU_WHO_AM_I, 1)[0]
    print(f"[MPU] WHO_AM_I = 0x{who:02X}  ({'OK' if who == 0x68 else 'UNEXPECTED'})")
    print("[MPU] Calibrating - keep board STILL for 2 s ...")
    time.sleep_ms(500)
    N = 200
    sax = say = saz = sgx = sgy = sgz = 0
    for _ in range(N):
        raw = _mpu_r(MPU_ACCEL_XOUT_H, 14)
        ax, ay, az = struct.unpack(">hhh", raw[0:6])
        gx, gy, gz = struct.unpack(">hhh", raw[8:14])
        sax += ax; say += ay; saz += az
        sgx += gx; sgy += gy; sgz += gz
        time.sleep_ms(5)
    off_ax = sax // N
    off_ay = say // N
    off_az = (saz // N) - int(ACCEL_SCALE)
    off_gx = sgx // N
    off_gy = sgy // N
    off_gz = sgz // N
    print(f"[MPU] Accel offsets: ({off_ax}, {off_ay}, {off_az})")
    print(f"[MPU] Gyro  offsets: ({off_gx}, {off_gy}, {off_gz})")
    print("[MPU] Calibration done.")
    return (off_ax, off_ay, off_az), (off_gx, off_gy, off_gz)

def mpu_read(accel_off, gyro_off):
    raw = _mpu_r(MPU_ACCEL_XOUT_H, 14)
    ax_r, ay_r, az_r = struct.unpack(">hhh", raw[0:6])
    gx_r, gy_r, gz_r = struct.unpack(">hhh", raw[8:14])
    ax = (ax_r - accel_off[0]) / ACCEL_SCALE
    ay = (ay_r - accel_off[1]) / ACCEL_SCALE
    az = (az_r - accel_off[2]) / ACCEL_SCALE
    gx = (gx_r - gyro_off[0])  / GYRO_SCALE
    gy = (gy_r - gyro_off[1])  / GYRO_SCALE
    gz = (gz_r - gyro_off[2])  / GYRO_SCALE
    roll  = math.degrees(math.atan2(ay, az))
    pitch = math.degrees(math.atan2(-ax, math.sqrt(ay*ay + az*az)))
    return {
        "ax": round(ax, 3), "ay": round(ay, 3), "az": round(az, 3),
        "gx": round(gx, 2), "gy": round(gy, 2), "gz": round(gz, 2),
        "roll": round(roll, 1), "pitch": round(pitch, 1),
    }


class OneWire:
    def __init__(self, pin):
        self._p = pin

    def reset(self):
        p = self._p
        p.init(Pin.OUT); p.value(0); time.sleep_us(480)
        p.init(Pin.IN);  time.sleep_us(70)
        present = (p.value() == 0)
        time.sleep_us(410)
        return present

    def _write_bit(self, bit):
        p = self._p
        p.init(Pin.OUT); p.value(0)
        if bit:
            time.sleep_us(1);  p.init(Pin.IN); time.sleep_us(60)
        else:
            time.sleep_us(60); p.init(Pin.IN); time.sleep_us(1)

    def _read_bit(self):
        p = self._p
        p.init(Pin.OUT); p.value(0); time.sleep_us(1)
        p.init(Pin.IN);  time.sleep_us(14)
        bit = p.value()
        time.sleep_us(45)
        return bit

    def write_byte(self, byte):
        for _ in range(8):
            self._write_bit(byte & 1)
            byte >>= 1

    def read_byte(self):
        val = 0
        for i in range(8):
            val |= self._read_bit() << i
        return val

    def strong_pullup(self, ms):
        p = self._p
        p.init(Pin.OUT); p.value(1)
        time.sleep_ms(ms)
        p.init(Pin.IN)


def _ow_crc8(data):
    crc = 0
    for byte in data:
        for _ in range(8):
            mix = (crc ^ byte) & 0x01
            crc >>= 1
            if mix:
                crc ^= 0x8C
            byte >>= 1
    return crc

def ds18b20_read(ow):
    if not ow.reset():
        return -999.0
    ow.write_byte(OW_SKIP_ROM)
    ow.write_byte(OW_CONVERT_T)
    ow.strong_pullup(800)
    if not ow.reset():
        return -999.0
    ow.write_byte(OW_SKIP_ROM)
    ow.write_byte(OW_READ_SCRATCH)
    scratch = bytearray(9)
    for i in range(9):
        scratch[i] = ow.read_byte()
    if _ow_crc8(scratch) != 0:
        return -998.0
    raw = (scratch[1] << 8) | scratch[0]
    if raw == 0x0000 or raw == 0x0550:
        return -997.0
    if raw & 0x8000:
        raw -= 65536
    return round(raw / 16.0, 2)


def adc_to_v(raw):
    return raw * VREF / ADC_MAX

def voltage_to_tds(v, temp=25.0):
    comp = 1.0 + TEMP_COMP_COEFF * (temp - 25.0)
    vc   = v / comp
    tds  = (133.42 * vc**3 - 255.86 * vc**2 + 857.39 * vc) * 0.5
    return round(max(0.0, tds), 1)

def raw_to_moisture(raw):
    pct = (MOISTURE_DRY_RAW - raw) / (MOISTURE_DRY_RAW - MOISTURE_WET_RAW) * 100.0
    return round(max(0.0, min(100.0, pct)), 1)


SEP = "-" * 62

def fmt_d(d):
    return f"{d:6.1f} cm" if d >= 0 else "  NO ECHO"

def print_telemetry(n, dist, mpu, temp, tds, moist):
    d1, d2, d3, nn, nd = dist
    print(f"\n{SEP}")
    print(f"  Loop #{n:05d}")
    print(SEP)
    print("  ULTRASONIC (HC-SR04)")
    print(f"    Sensor 1  (GPIO  9/10) : {fmt_d(d1)}")
    print(f"    Sensor 2  (GPIO 11/12) : {fmt_d(d2)}")
    print(f"    Sensor 3  (GPIO 13/14) : {fmt_d(d3)}")
    if nd >= 0:
        print(f"  >> NEAREST WALL : {nn}  ->  {nd:.1f} cm")
    else:
        print("  >> NEAREST WALL : no valid reading")
    print()
    print("  MPU-6050  (SDA=GPIO4  SCL=GPIO5)")
    print(f"    Accel  X={mpu['ax']:+.3f} g   Y={mpu['ay']:+.3f} g   Z={mpu['az']:+.3f} g")
    print(f"    Gyro   X={mpu['gx']:+6.2f}/s  Y={mpu['gy']:+6.2f}/s  Z={mpu['gz']:+6.2f}/s")
    print(f"    Roll  {mpu['roll']:+6.1f}    Pitch {mpu['pitch']:+6.1f}")
    print()
    print("  DS18B20  (GPIO 2 / 1-Wire)")
    if temp > -900:
        print(f"    Temperature : {temp:.2f} C")
    elif temp == -999.0:
        print("    Temperature : *** NO DEVICE - check GPIO 2 wiring ***")
    elif temp == -998.0:
        print("    Temperature : *** CRC FAIL - check 4.7k pull-up to 3.3V ***")
    elif temp == -997.0:
        print("    Temperature : *** DEFAULT VALUE - conversion did not run ***")
    else:
        print("    Temperature : *** UNKNOWN ERROR ***")
    print()
    print("  TDS SENSOR  (GPIO 27 / ADC1)")
    print(f"    TDS : {tds:.1f} ppm")
    print()
    print("  SOIL MOISTURE  (GPIO 26 / ADC0)")
    print(f"    Moisture : {moist:.1f} %")
    print()
    print("  DC MOTORS -> FULL SPEED FORWARD  (ENA=GPIO16  ENB=GPIO21)")
    print(SEP)


def main():
    print()
    print("=" * 62)
    print("      TERRASKIPPER  -  Pico 2 W  Live Telemetry")
    print("=" * 62)

    try:
        accel_off, gyro_off = mpu_init_and_calibrate()
        mpu_ok = True
    except Exception as e:
        print(f"[MPU] INIT FAILED: {e}")
        accel_off = gyro_off = (0, 0, 0)
        mpu_ok = False

    _mpu_zero = {"ax": 0, "ay": 0, "az": 0,
                 "gx": 0, "gy": 0, "gz": 0,
                 "roll": 0, "pitch": 0}

    ow = OneWire(ow_pin)

    print("\n[MOTOR] Starting motors - full speed forward ...")
    motors_forward_full()

    servo_cw(sv1, speed=1.0)
    servo_angle(sv2, 90)
    servo_angle(sv3, 90)

    print("[DS18B20] First temperature read ...")
    last_temp  = ds18b20_read(ow)
    TEMP_EVERY = 20
    temp_ctr   = 0

    print("\n[MAIN] Entering main loop ...\n")
    loop_n = 0

    while True:
        t0 = time.ticks_ms()
        loop_n += 1

        dist_data = read_all_ultrasonic()

        if mpu_ok:
            try:
                mpu_data = mpu_read(accel_off, gyro_off)
            except Exception as e:
                print(f"[MPU] read error: {e}")
                mpu_data = _mpu_zero
        else:
            mpu_data = _mpu_zero

        temp_ctr += 1
        if temp_ctr >= TEMP_EVERY:
            temp_ctr = 0
            try:
                last_temp = ds18b20_read(ow)
            except Exception as e:
                print(f"[DS18B20] error: {e}")

        tds_v   = adc_to_v(adc_tds.read_u16())
        tds_ppm = voltage_to_tds(tds_v, temp=last_temp if last_temp > -900 else 25.0)

        moist_pct = raw_to_moisture(adc_moisture.read_u16())

        print_telemetry(loop_n, dist_data, mpu_data, last_temp, tds_ppm, moist_pct)

        wait = LOOP_PERIOD_MS - time.ticks_diff(time.ticks_ms(), t0)
        if wait > 0:
            time.sleep_ms(wait)


if __name__ == "__main__":
    main()
